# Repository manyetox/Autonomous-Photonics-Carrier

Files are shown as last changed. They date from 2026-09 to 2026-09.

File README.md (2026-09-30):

# Autonomous-Photonics-Carrier

**A source-available mobile robotics platform for autonomous and reconfigurable free-space photonics experiments.**

This repository contains the electronics, fabrication files, preliminary embedded firmware, and research documentation for my UCL Electrical and Electronic Engineering third-year BEng project. The carrier is intended to move standard optical hardware around a tabletop, estimate its own motion from complementary sensors, and ultimately support closed-loop optical experiment setup and alignment.

> **Project status — September 2026:** the **Platform V2 hardware design is finished**. Manufacturing and assembly are **partially complete and awaiting remaining parts**. The V2 main controller, motor/IMU board, and MA730 wheel-encoder board have been bench validated. The PAW3395 optical-flow board is the only current board that has not yet been experimentally validated. Full multi-sensor autonomous operation and the experiment-control software are still under development.

<p align="center">
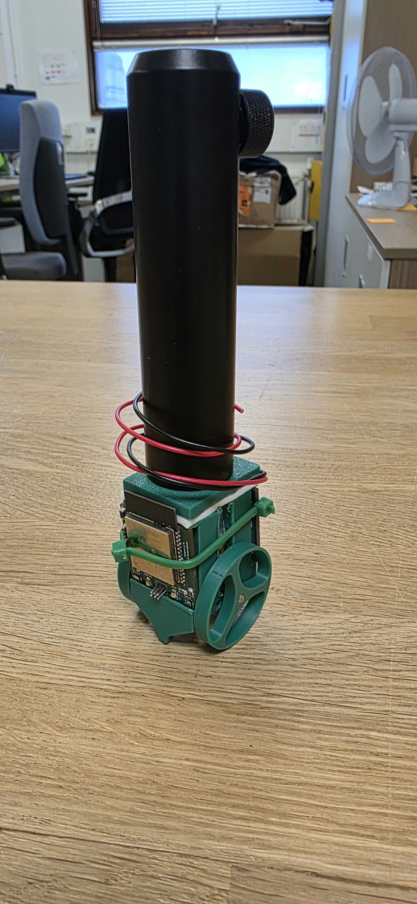
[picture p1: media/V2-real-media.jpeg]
Partially assembled Platform V2 carrier — front view
  
  &nbsp;&nbsp;
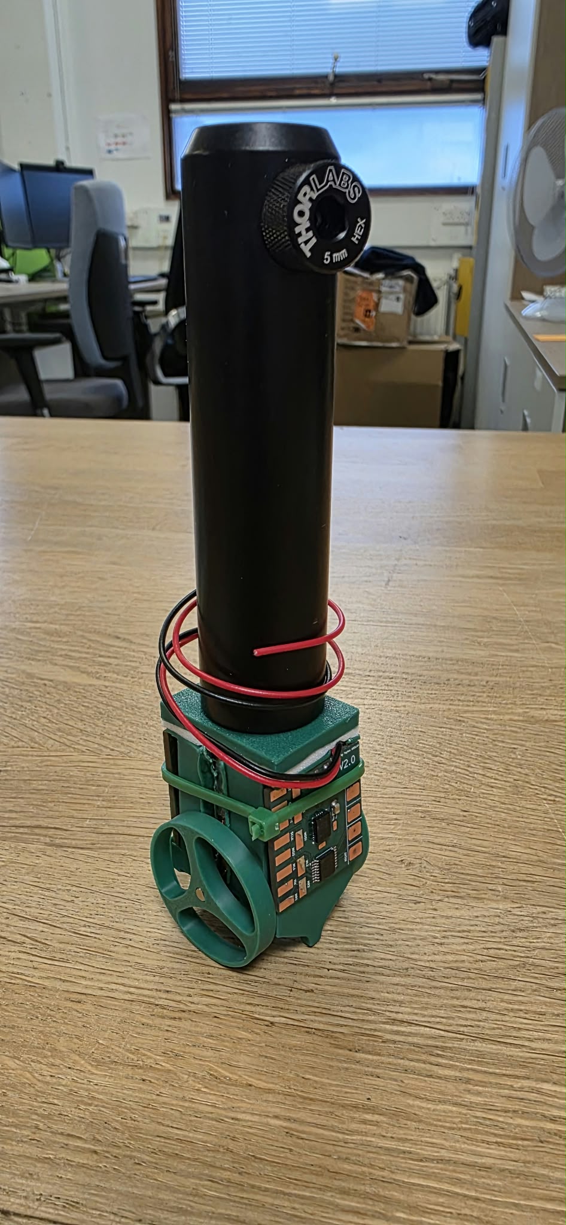
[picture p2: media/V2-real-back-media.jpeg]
Partially assembled Platform V2 carrier — rear view
  
</p>

<p align="center"><em>Current Platform V2 hardware during assembly. Front and rear views of the mobile carrier with the optical-post interface installed. The mechanical and electrical design is complete, while final assembly is still awaiting the remaining parts.</em></p>

## Read this first: platform versions are not board revisions

There are only **two photonics-carrier platform generations** in this repository:

| System generation | Meaning | Status |
|---|---|---|
| **Platform V1** | First integrated/monolithic autonomous-photonics carrier electronics | Historical, validated, superseded by V2 |
| **Platform V2** | Current modular carrier architecture | Current design; system assembly in progress |

The numbers on individual V2 PCBs are **board-local revisions**, not new carrier generations. For example, **OFS-R2.1.1** means *Optical-Flow Sensor board revision 2.1.1*; it is still part of **Platform V2**. The same applies to **MB-R2.1**, **MDI-R2.0**, and **ENC-R1.0**.

See [`VERSIONING.md`](VERSIONING.md) before using fabrication files.

## Why this project exists

Free-space optical experiments are normally assembled and aligned manually. Even a simple setup can require repeated positioning of posts, lenses, polarisers, sources, detectors, and cameras. The long-term research question behind this project is whether a low-cost fleet of mobile optomechanical carriers can make parts of that process **reconfigurable, repeatable, measurable, and eventually autonomous**.

This repository focuses on the carrier layer: motion, embedded electronics, local sensing, and the interfaces needed for higher-level perception and closed-loop experiment control. It does **not** claim that autonomous optical alignment has already been solved; that is the experimental work this platform is intended to enable.

## Research questions

The project is being developed as an experimental research platform rather than only as a mobile-robot hardware build. The central question is:

> **Can a self-propelled optical post-holder module combine mobile positioning, multi-sensor localisation, and optical feedback to autonomously reconstruct and align repeatable free-space photonics experiments?**

The current evaluation is organised around six questions:

1. **Coarse positioning accuracy and repeatability** — How accurately can a carrier reach a commanded planar pose \((x, y, \psi)\), and how closely can it return to that pose over repeated trials? How are the results affected by approach direction, travel distance, wheel slip, payload, and table-surface conditions?
2. **Stationary stability** — How much translational and angular drift occurs while the carrier remains stationary on its wheels? How are the results affected by motor-hold strategy, payload centre of mass, battery voltage, and measurement duration?
3. **Localisation and sensor fusion** — What accuracy and robustness can be achieved using the MA730 wheel encoders, PAW3395 optical-flow sensor, BNO086 IMU, and planned overhead visual fiducials individually and in combination? In particular, can the fused estimate remain useful during wheel slip, short visual occlusion, and accumulated odometry drift?
4. **Closed-loop optical alignment and recovery** — Can optical feedback compensate for the residual mechanical error remaining after mobile positioning? What alignment error, convergence time, capture range, success rate, and recovery behaviour can be achieved?
5. **Experiment reconstruction and operating range** — Can one or more carriers reconstruct the same optical configuration on separate occasions and reproduce the same measurement? For which beam sizes, propagation distances, wavelengths, and classes of tabletop experiment is the achieved positioning performance sufficient?
6. **Compatibility, cost, and scalability** — Can the platform carry standard optical posts and common holders without permanent modification? What payload, centre-of-mass height, battery runtime, and cost per carrier are practical, and how does operation change when multiple carriers share the same workspace?

These questions are intended to map directly onto measurable experiments. Results will only be reported after the relevant mechanical, electronic, localisation, and optical-control subsystems have been implemented and experimentally characterised.

> **Design-evolution note:** the earliest research framing included an on-carrier screw-and-flexure fine-positioning stage and UWB ranging. Those ideas belong to the earlier design direction and are **not core Platform V2 subsystems**. Platform V2 instead focuses on a modular mobile carrier using wheel encoding, bottom optical flow, inertial sensing, planned overhead visual localisation, and later optical feedback. Fine optomechanical correction can be evaluated as a separate layer if required.

## Current Platform V2 architecture

```mermaid
flowchart LR
    B["1S LiPo / external power"] --> MB["MB-R2.1<br/>ESP32-WROOM-32UE mainboard"]
    MB --> MDI["MDI-R2.0<br/>TC78H651 + BNO086"]
    MDI --> LM["Left DC gearmotor"]
    MDI --> RM["Right DC gearmotor"]

    MB --> OFS["OFS-R2.1.1<br/>PAW3395 optical-flow board"]
    MB --> ENC["ENC-R1.0<br/>MA730 wheel encoder boards"]

    OFS --> REL["Relative tabletop motion"]
    ENC --> WHEEL["Wheel angle / odometry"]
    MDI --> IMU["Inertial orientation / motion"]

    CAM["Overhead camera + fiducials<br/>planned system layer"] --> HOST["Host perception + experiment software<br/>planned"]
    HOST --> MB

    REL --> FUSION["Pose estimation / sensor fusion<br/>planned"]
    WHEEL --> FUSION
    IMU --> FUSION
    CAM --> FUSION
```

The V2 redesign deliberately separates functions across small PCBs. This makes the system easier to manufacture, debug, replace, and revise than V1's dense integrated board.

### V2 hardware at a glance

| Board ID | Function | Key devices | PCB | Current state |
|---|---|---|---|---|
| **MB-R2.1** | Main controller / power / breakout | ESP32-WROOM-32UE, NCP186 3.3 V LDO | 4-layer, ~25 × 27.1 mm | **Validated** |
| **MDI-R2.0** | Dual motor drive + IMU | TC78H651FGN, BNO086 | 4-layer, ~25 × 27 mm | **Validated** |
| **OFS-R2.1.1** | Bottom optical-flow sensing | PAW3395, AP2127K-1.8 | 2-layer, ~19.3 × 24.0 mm | **Not yet experimentally validated** |
| **ENC-R1.0** | Wheel-angle sensing | MA730 magnetic encoder | 2-layer, ~20 × 16.8 mm | **Validated** |

<p align="center">
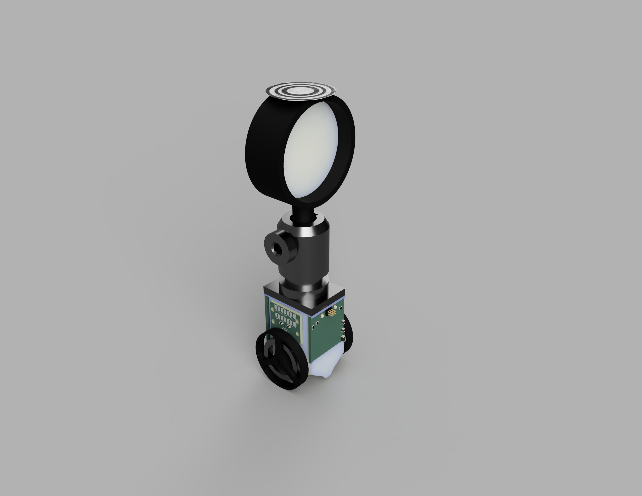
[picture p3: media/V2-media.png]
Platform V2 mechanical and electronics render
  
</p>

<p align="center"><em>Platform V2 design render. The current generation uses a modular electronics architecture so sensing, motor control, and the main controller can be manufactured, debugged, and revised independently.</em></p>

## Design evolution

### Platform V1 — integrated architecture

V1 placed most functions on one approximately **50 × 50 mm, 8-layer PCB**. The design included an **ESP32-S3-WROOM-1**, **DWM3000 UWB**, **BNO086 IMU**, **two TMC5041 stepper-controller ICs**, **DRV8231 motor-driver stages**, and the associated power and USB circuitry. It was a useful integration exercise and was built around the original concept of combining coarse mobile motion with local stepper/flexure positioning.

<p align="center">
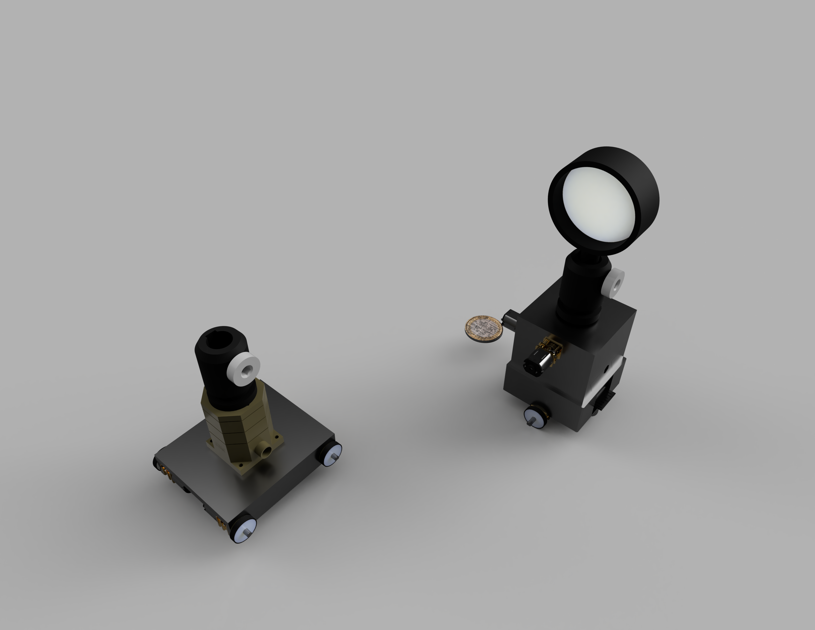
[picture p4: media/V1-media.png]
Platform V1 carrier concept render
  
</p>

<p align="center"><em>Platform V1 concept. The first carrier generation combined the mobile base with local optomechanical positioning and concentrated most of the electronics onto a single integrated PCB.</em></p>

### Why V2 changed direction

The current architecture intentionally moves away from putting every possible function on one carrier PCB. The main reasons were:

- **Modularity:** sensor and motor electronics can be revised without remanufacturing the controller.
- **Debuggability:** faults can be isolated board-by-board.
- **Lower manufacturing risk:** smaller boards and fewer tightly coupled subsystems.
- **Sensor strategy:** PAW3395 relative optical tracking, MA730 wheel angle, BNO086 inertial data, and planned overhead fiducials provide complementary information without retaining UWB as a core requirement.
- **Fine alignment separation:** the mobile base focuses on coarse positioning and repeatability. Very fine optical correction can be implemented as a separate optomechanical layer instead of forcing stepper/flexure hardware into every mobile carrier.
- **Cost and repeatability:** the architecture is intended to scale to multiple carriers, so unnecessary per-carrier complexity matters.

The V1 source is retained because it documents the design path and may still be useful to researchers interested in a more integrated architecture.

### Legacy reference — pre-project mobile robotics hardware

Before the dedicated photonics-carrier generations, I developed a more general mobile-robot electronics platform. It is retained in [`hardware/legacy-reference`](hardware/legacy-reference/) because several practical design lessons carried into this project, but it is **not Platform V0** and should not be treated as part of the carrier version sequence.

<p align="center">
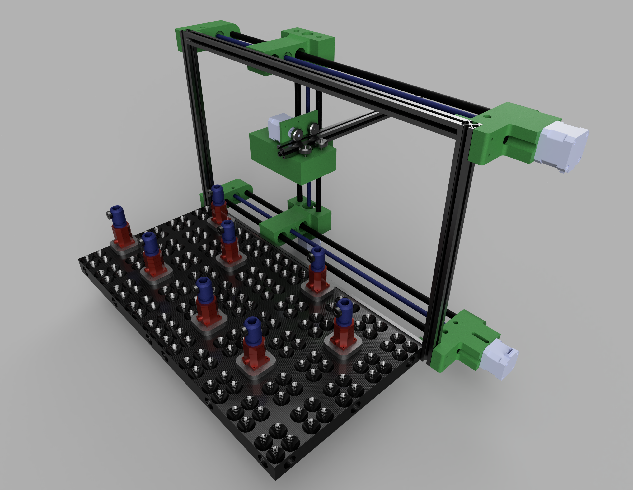
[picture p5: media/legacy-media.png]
Legacy mobile robotics reference hardware
  
</p>

<p align="center"><em>Legacy mobile-robot reference design retained for engineering context. It predates the autonomous-photonics carrier and is included only to document relevant design heritage.</em></p>

## Repository map

```text
Autonomous-Photonics-Carrier/
├── hardware/
│   ├── platform-v1/                 # Historical integrated carrier
│   ├── platform-v2/
│   │   ├── mainboard/MB-R2.1/
│   │   ├── motor-driver-imu/MDI-R2.0/
│   │   ├── optical-flow/OFS-R2.1.1/
│   │   └── wheel-encoder/ENC-R1.0/
│   └── legacy-reference/            # Pre-project robot electronics; not a platform version
├── firmware/preliminary/            # Safe preliminary ESP32 firmware scaffold
├── software/                        # Planned host-side autonomy / experiment software
├── docs/                            # Architecture, methods, validation, manufacturing notes
├── data/                            # Experimental-data conventions; no results claimed yet
├── media/                           # Image/video placeholders
├── VERSIONING.md
├── CHANGELOG.md
├── CITATION.cff
└── LICENSE.md
```

## Hardware source and fabrication files

Native **KiCad source files** are provided alongside fabrication outputs. Current fabrication packages are separated from superseded board revisions so that a Gerber revision cannot be mistaken for a platform generation.

Start here:

- [Platform V1 hardware](hardware/platform-v1/README.md)
- [Platform V2 hardware](hardware/platform-v2/README.md)
- [V2 mainboard — MB-R2.1](hardware/platform-v2/mainboard/MB-R2.1/README.md)
- [Motor/IMU — MDI-R2.0](hardware/platform-v2/motor-driver-imu/MDI-R2.0/README.md)
- [Optical flow — OFS-R2.1.1](hardware/platform-v2/optical-flow/OFS-R2.1.1/README.md)
- [Wheel encoder — ENC-R1.0](hardware/platform-v2/wheel-encoder/ENC-R1.0/README.md)
- [Manufacturing guide](docs/manufacturing.md)

The CSV BOMs in the board folders were auto-extracted from the KiCad PCB files to make review easier. **They are not a substitute for checking the schematic and part datasheets before ordering.**

## Preliminary firmware

A deliberately conservative PlatformIO/Arduino scaffold is included in [`firmware/preliminary`](firmware/preliminary/README.md). It establishes the intended embedded-software structure, status reporting, motor-control abstraction, serial command interface, and placeholders for BNO086, PAW3395, and MA730 integration.

It is **not the final autonomy firmware** and it is **not presented as experimentally validated software**. Peripheral signal-to-GPIO assignment is left disabled by default wherever the uploaded hardware files do not prove the final system interconnect unambiguously. This prevents a public repository from presenting guessed pin mappings as fact.

The preliminary firmware and parts of the repository/software scaffolding were prepared with assistance from **OpenAI ChatGPT 5.6** and then reviewed against the project hardware files. See [`AI_ASSISTANCE.md`](AI_ASSISTANCE.md).

## Planned sensing and autonomy stack

The intended estimation hierarchy is complementary rather than relying on a single sensor:

1. **Wheel angle / odometry:** MA730 magnetic encoders provide direct rotational information at the drivetrain.
2. **Bottom optical flow:** PAW3395 provides high-rate relative motion against the tabletop and can expose wheel-slip/odometry disagreement.
3. **IMU:** BNO086 provides inertial orientation/motion information and short-term dynamic context.
4. **Overhead fiducials:** a camera observing AprilTags or similar fiducials is planned as a global absolute pose reference and recovery mechanism.
5. **Optical feedback:** experimental signals can eventually be incorporated into the control loop so the carrier optimises the *optical result*, not only geometric pose.

Sensor fusion, global localisation, multi-carrier coordination, and optical-feedback optimisation are **planned software work**; they are not claimed as completed results in this repository.

## Research measurements this platform is intended to support

The repository is organised so that later results can be reproduced rather than reported only as a final demo. The principal measurements are:

- planar pose accuracy in **x, y, and yaw** against an external reference;
- **return-to-pose repeatability** over repeated move-away-and-return cycles;
- **stationary drift** and accumulated odometry drift;
- wheel-encoder, optical-flow, and IMU disagreement under controlled motion;
- recovery from deliberate slip or localisation error;
- carrier-to-carrier consistency if multiple units are built;
- cost per carrier and sensitivity to inexpensive mechanical components;
- success rate of a defined optical alignment task.

See [`docs/research-methodology.md`](docs/research-methodology.md) and [`docs/validation.md`](docs/validation.md). Until those experiments are complete, target resolutions or simulated estimates should not be read as measured performance.

For the research context behind the architecture, see [`docs/related-work.md`](docs/related-work.md).

## Research context and selected related work

This project sits between **robotic optical alignment**, **autonomous laboratories**, and **mobile multi-sensor robotics**. The most directly relevant prior work is summarised here; the longer discussion belongs in [`docs/related-work.md`](docs/related-work.md).

- **OptoMate / AI-Driven Robotics for Optics** demonstrates a general-purpose robotic approach to physically assembling and aligning free-space optical experiments using computer vision, robotic manipulation, and AI-assisted control [1]. It is a particularly close research neighbour, but it uses an external robotic manipulator rather than making each optical element independently mobile.
- **Choi et al.** present a closed-loop framework for robotic optical assembly, alignment, and self-recovery [2]. This is directly relevant to the carrier's long-term objective of detecting misalignment, correcting it from measurement feedback, and recovering after a disturbance.
- **Rakhmatulin et al.** review automated laser-optics alignment, including optimisation and machine-learning approaches [3]. Their review motivates treating the optical signal itself as a feedback variable rather than assuming that geometric positioning alone is sufficient.
- **Fang and Savransky** show automated alignment of a reconfigurable optical system using focal-plane sensing and Kalman filtering [4], providing an example of image-based estimation driving corrective optical motion.
- **Szymanski et al.** demonstrate the broader self-driving-laboratory concept in which robotics, measurement, and computational decision-making form a closed experimental loop [5]. The present project explores a different physical layer: making the experimental optical hardware itself reconfigurable on the tabletop.

Commercial active-alignment systems from companies such as Physik Instrumente provide useful industrial context: high-precision automated optical alignment is already practical, but such systems are generally built around dedicated stages and predefined alignment tasks rather than low-cost independently mobile optical carriers [6].

The distinction matters: this repository does **not** claim that the individual techniques above are new. The research question is whether coarse mobile positioning, complementary low-cost sensing, standard optomechanical compatibility, and closed-loop optical feedback can be combined into a scalable carrier architecture for reconfigurable free-space experiments.

## Selected references

1. S. Z. Uddin, S. Vaidya, S. Choudhary, Z. Chen, R. K. Salib, L. Huang, D. R. Englund, and M. Soljačić, **“AI-Driven Robotics for Optics,”** arXiv:2505.17985, 2025. https://doi.org/10.48550/arXiv.2505.17985
2. S. Choi, S. Vaidya, C. Silva, S. Z. Uddin, S. B. Shuvo, S. Choudhary, and M. Soljačić, **“A Framework for Closed-Loop Robotic Assembly, Alignment and Self-Recovery of Precision Optical Systems,”** arXiv:2603.21496, 2026. https://doi.org/10.48550/arXiv.2603.21496
3. I. Rakhmatulin, D. Risbridger, R. Carter, M. J. D. Esser, and M. S. Erden, **“A Review of Automation of Laser Optics Alignment with a Focus on Machine Learning Applications,”** *Optics and Lasers in Engineering*, vol. 173, 107923, 2024. https://doi.org/10.1016/j.optlaseng.2023.107923
4. J. Fang and D. Savransky, **“Automated Alignment of a Reconfigurable Optical System Using Focal-Plane Sensing and Kalman Filtering,”** arXiv:1608.07550, 2016. https://arxiv.org/abs/1608.07550
5. N. J. Szymanski *et al.*, **“An Autonomous Laboratory for the Accelerated Synthesis of Inorganic Materials,”** *Nature*, vol. 624, pp. 86–91, 2023. https://doi.org/10.1038/s41586-023-06734-w
6. PI (Physik Instrumente), **“Active Photonics Alignment Systems / Fiber Optic Alignment Stages,”** product and application documentation. https://www.pi-usa.us/en/products/photonics-alignment-solutions

## Project information

**Author:** Taylan Arslan  
**Programme:** UCL Electrical and Electronic Engineering — BEng third-year project, 2026–27  
**Project supervisor:** Prof. Kaan Akşit  
**EEE co-supervisor:** Thomas Gilbert

The supervisors are acknowledged for academic supervision; this repository is maintained by the author and is **not an official UCL product or endorsement**.

## Contributing

Research feedback, reproducibility reports, bug findings, and non-commercial improvements are welcome. Please read [`CONTRIBUTING.md`](CONTRIBUTING.md) before opening a pull request. In particular, use the versioning vocabulary above when discussing hardware revisions.

## Licensing

This repository is intentionally **source-available for non-commercial research, education, and personal experimentation**, but it does **not** grant commercial-use rights under its public licences.

- Hardware design files, documentation, diagrams, and repository media: **CC BY-NC 4.0**.
- Firmware and software: **PolyForm Noncommercial License 1.0.0**.
- Commercial use requires a **separate written commercial licence** from the author.

Because of the non-commercial restriction, this project should **not** be described as OSHWA-compliant “open-source hardware.” See [`LICENSE.md`](LICENSE.md) for the exact scope and important IP limitations.

## Safety and experimental responsibility

This is research hardware, not a certified product. Re-check power rails, polarity, motor current, battery protection/charging, connector orientation, clearances, and fabrication outputs before use. If the carrier is used around lasers or other optical sources, follow the laboratory's laser-safety procedures; this repository does not replace a risk assessment or device datasheet.

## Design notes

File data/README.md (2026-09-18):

# Experimental data

No positioning-performance dataset is claimed in this repository snapshot yet.

When experiments begin, use the structure in `docs/reproducibility.md`. Keep raw sensor/ground-truth logs immutable and store processed results separately.

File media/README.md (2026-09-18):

# Media placeholders

The repository is intentionally usable before final photographs are ready. Suggested filenames to add later:

- `hero-v2-carrier.jpg` — assembled Platform V2 carrier / main README image.
- `platform-v1-board.jpg` — assembled or rendered V1 integrated PCB.
- `v2-electronics-stack.jpg` — V2 mainboard and daughterboards together.
- `mb-r2.1.jpg` — V2 mainboard close-up.
- `mdi-r2.0.jpg` — motor/IMU board close-up.
- `ofs-r2.1.1.jpg` — PAW3395 board underside/lens assembly.
- `enc-r1.0.jpg` — MA730 encoder with magnet arrangement.
- `carrier-chassis.jpg` — mechanical carrier and optical post mount.
- `validation-setup.jpg` — overhead camera / tabletop test setup.
- `optical-demo.jpg` — eventual optical alignment experiment.

The visible text placeholders in the Markdown files can be replaced by normal Markdown images when these files are available.

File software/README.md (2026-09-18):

# Host software — planned

The host-side autonomy and experiment-control software is still planned rather than presented as complete. This directory documents the intended boundaries so that later software development remains compatible with the hardware.

## Planned modules

- **Global perception:** overhead camera calibration, fiducial/AprilTag detection, carrier identification, and global x/y/yaw pose.
- **Pose fusion:** combine camera, wheel angle, PAW3395 relative motion, and BNO086 information with explicit uncertainty handling.
- **Motion planning/control:** convert target table poses into carrier trajectories while handling obstacles and multiple carriers.
- **Experiment model:** represent optical components, carrier identities, and desired experimental topology.
- **Optical feedback:** use detector/camera/experiment measurements to refine physical alignment.
- **Logging:** synchronised sensor, command, pose, and optical-data capture for reproducible experiments.

## Interface philosophy

The embedded controller should own fast local actuation and low-level safety; the host should own global perception, experiment logic, optimisation, and data logging. This split keeps high-level research algorithms easy to modify without making the real-time motor-control path depend on a desktop process.

## AI assistance

Initial software architecture notes and the preliminary embedded scaffold were prepared with some assistance from OpenAI ChatGPT 5.6. Future implemented algorithms should be reviewed, tested, and documented in the same way as any other research code.

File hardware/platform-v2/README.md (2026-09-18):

# Platform V2 — current modular architecture

Platform V2 is the current carrier architecture. It is a **system generation**, not a PCB revision number.

Current boards:

- **MB-R2.1** — main controller/power/breakout
- **MDI-R2.0** — motor driver + BNO086 IMU
- **OFS-R2.1.1** — PAW3395 optical-flow sensor
- **ENC-R1.0** — MA730 wheel encoder

The electronics design is finished. Manufacturing/assembly of the complete carrier is still in progress while remaining parts arrive.

Three of the four current V2 board designs have been bench validated; OFS-R2.1.1 remains to be experimentally validated.

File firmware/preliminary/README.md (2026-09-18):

# Preliminary Platform V2 firmware scaffold

This is a **starting point**, not finished autonomous-carrier firmware.

It is intentionally conservative:

- targets the ESP32-WROOM-32UE main controller through the generic PlatformIO `esp32dev` board definition;
- controls the confirmed **IO13 status LED**;
- exposes a raw ADC diagnostic for the mainboard ADC-labelled net;
- defines a dual-H-bridge motor abstraction but refuses to drive motors until final GPIO mappings are supplied;
- provides serial commands for status/stop/motor testing;
- provides explicit placeholder interfaces for BNO086, PAW3395, and MA730 integration;
- performs no autonomous motion at boot.

The daughterboard connector signal names are known from KiCad, but the final physical signal-to-ESP32 interconnect is not encoded here unless it is unambiguous. This is deliberate: public firmware should not turn a guessed harness mapping into an apparent design fact.

## Build

Install PlatformIO and run:

```bash
pio run
```

Upload/monitor commands depend on the programmer/serial arrangement used with the TC2030/mainboard.

## First bring-up sequence

1. Build and flash with all peripheral pin assignments left disabled.
2. Confirm boot messages and IO13 LED heartbeat.
3. Confirm the actual daughterboard-to-mainboard wiring from the assembled carrier.
4. Populate `include/board_config.h` with the final GPIO numbers.
5. Test one motor at a time with the carrier lifted and a current-limited supply.
6. Integrate BNO086, MA730, then PAW3395 drivers individually.
7. Only after sensor sign/frame checks should closed-loop motion be enabled.

## AI assistance

This preliminary scaffold was written with some assistance from **OpenAI ChatGPT 5.6**, using the project's KiCad net names and existing architecture as context. It has not yet been validated as the final firmware and should be reviewed against device datasheets during implementation.

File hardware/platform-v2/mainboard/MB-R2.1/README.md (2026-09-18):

# MB-R2.1 — Platform V2 mainboard

**Platform:** V2  
**Board revision:** MB-R2.1  
**Status:** validated; current  
**PCB:** 4 layers, approximately 25 × 27.1 mm

## Function

MB-R2.1 is the central controller and power/breakout board. It intentionally avoids embedding every sensor/actuator subsystem so that daughterboards can be changed independently.

## Key hardware

- ESP32-WROOM-32UE
- NCP186-series 3.3 V LDO design
- TC2030 programming connector
- two 13-pin expansion headers
- IO13 user/status LED
- 3.3 V power indicator

See `docs/interfaces-and-pinouts.md` for connector nets.

## Fabrication

Use only `fabrication/current/MB-R2.1-gerbers.zip` for the current board. `archive/MB-R2.0-gerbers-superseded.zip` is kept only for design history.

> **Image placeholder:** I will add a photograph of the assembled MB-R2.1 here later.

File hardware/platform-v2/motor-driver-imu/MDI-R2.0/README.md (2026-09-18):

# MDI-R2.0 — motor driver + IMU

**Platform:** V2  
**Board revision:** MDI-R2.0  
**Status:** validated; current  
**PCB:** 4 layers, approximately 25 × 27 mm

## Function

This daughterboard combines low-speed differential-drive actuation with inertial sensing.

## Key hardware

- **TC78H651FGN** dual H-bridge motor driver
- **BNO086** 9-axis smart IMU
- SPI-oriented IMU interface signals
- separate motor output pads

The design is intended for the low-speed DC-gearmotor V2 drivetrain rather than the V1 stepper/flexure architecture.

See `docs/interfaces-and-pinouts.md` for the 13-pin connector net names.

> **Image placeholder:** I will add the assembled motor/IMU board and its motor wiring here later.

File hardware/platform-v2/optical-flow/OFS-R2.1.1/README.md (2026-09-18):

# OFS-R2.1.1 — PAW3395 optical-flow sensor

**Platform:** V2  
**Board revision:** OFS-R2.1.1  
**Status:** current design; **not yet experimentally validated**  
**PCB:** 2 layers, approximately 19.3 × 24.0 mm

## Function

This board mounts a bottom-facing PAW3395 optical tracking sensor so the carrier can measure relative motion against the tabletop independently of wheel rotation.

## Key hardware

- PAW3395 optical tracking sensor
- AP2127K-1.8 local 1.8 V LDO
- SPI (`SCLK`, `MOSI`, `MISO`, `nCS`)
- `MOTION` output
- lens/mechanical optical stack

The current schematic specifies **R3 = 2 MΩ**.

This board should not be described as working until the 1.8 V rail, SPI initialisation, motion data, lens height, and calibrated displacement have been tested on the assembled hardware.

> **Image placeholder:** I will add a photograph showing the PAW3395 lens and underside mounting here after validation.

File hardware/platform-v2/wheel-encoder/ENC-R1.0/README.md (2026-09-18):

# ENC-R1.0 — MA730 wheel encoder

**Platform:** V2  
**Board revision:** ENC-R1.0  
**Status:** validated; current  
**PCB:** 2 layers, approximately 20 × 16.8 mm

## Function

ENC-R1.0 measures wheel/shaft angle using the **MA730 magnetic angle sensor**. It replaces earlier exploration of sparse Hall-sensor edge counting with a more direct angle-sensing approach.

## Interfaces

- SPI: MOSI, MISO, SCLK, CS
- 3.3 V and GND
- optional A/B/Z outputs
- PWM output
- MGL/MGH magnetic-field diagnostic outputs

The magnetic target and air gap are part of the measurement system. Experimental records should identify the magnet geometry and mechanical spacing.

> **Image placeholder:** I will add the encoder mounted next to the final wheel/shaft magnet here later.

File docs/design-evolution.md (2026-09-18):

# Design evolution and engineering rationale

## Pre-project legacy controller

The repository includes an older general-purpose ESP32 robot-controller PCB under `hardware/legacy-reference/`. It is included only to show the engineering background that informed later motor-control and embedded-PCB decisions. It is **not Platform V0 or Platform V1**.

## Platform V1: integration-first

The first photonics-specific carrier used a dense 8-layer board. The architecture attempted to keep coarse motion, UWB localisation, inertial sensing, local stepper control, USB protection, and power electronics on one PCB. That approach offered compact integration, but it also coupled many experimental assumptions into one expensive board spin.

The most important V1 elements visible in the source are:

- ESP32-S3-WROOM-1 controller;
- DWM3000 UWB module;
- BNO086 IMU;
- two TMC5041 stepper-controller ICs;
- DRV8231 motor-driver stages;
- TPS56528DDA power stage;
- a 50 × 50 mm, 8-layer PCB.

The local stepper/flexure concept made sense when the carrier was expected to perform coarse and fine motion itself. As the project matured, it became clearer that the mobile base and the fine optomechanical stage have different engineering requirements.

## Platform V2: modularity-first

V2 separates the carrier into replaceable functions. The mainboard is small and generic; the motor/IMU, optical-flow, and wheel-angle functions live on separate boards. This change supports several research goals:

- cheaper iteration on one subsystem;
- clearer fault isolation;
- easier comparison of alternative sensors;
- less dependence on a single monolithic PCB spin;
- simpler scaling to several carriers;
- easier future replacement of the MCU or sensor board.

### Why UWB is no longer core

UWB was useful as a coarse global-localisation idea, but the combination of overhead fiducials, bottom optical flow, wheel angle, and IMU data better matches the tabletop scale of the experiment while reducing radio hardware and calibration complexity. UWB remains documented in V1 rather than being silently erased from the design history.

### Why the stepper/flexure subsystem was removed from V2

Fine optical alignment can require much finer motion and better stiffness than a low-cost mobile base naturally provides. Instead of asking every carrier to contain a complete fine XYZ/yaw mechanism, V2 treats the mobile base as a coarse positioning and sensing platform. A premade piezo/fine stage or experiment-specific adjustment module can be added above the carrier when needed.

### Why PAW3395

The PAW3395 path was chosen after looking for a compact, actively available optical-tracking sensor suitable for high-resolution relative motion. It provides a direct relative-motion signal at the bottom of the carrier and gives the estimator information that is independent of wheel rotation.

### Why MA730

Early encoder exploration considered discrete magnets and Hall sensors. The current board instead uses an MA730 magnetic angle encoder. That moves the design from sparse edge counting toward direct angular measurement and also exposes A/B/Z and diagnostic outputs for alternative experiments.

## Academic interpretation

V1 and V2 should be treated as different experimental hardware architectures, not as a claim that V2 is already proven superior in measured localisation performance. V2 is preferred because of engineering modularity and the current research direction; quantitative comparison requires data.

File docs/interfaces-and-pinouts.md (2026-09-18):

# Electrical interfaces and pinouts

These tables are extracted from the current uploaded KiCad PCB net names. They document what the boards expose without inventing an unverified system-level harness mapping.

## MB-R2.1 mainboard

### J2 — 13-pin expansion header

| Pin | Net |
|---:|---|
| 1 | +3.3V |
| 2 | GND |
| 3 | IO_analog_ADC |
| 4 | IO34 |
| 5 | IO35 |
| 6 | IO32 |
| 7 | IO33 |
| 8 | IO25 |
| 9 | IO26 |
| 10 | IO27 |
| 11 | IO14 |
| 12 | IO12 |
| 13 | IO13 |

### J3 — 13-pin expansion header

| Pin | Net |
|---:|---|
| 1 | GND |
| 2 | IO23 |
| 3 | IO22-SCL |
| 4 | IO21-SDA |
| 5 | IO19 |
| 6 | IO18 |
| 7 | IO17 |
| 8 | IO16 |
| 9 | IO4 |
| 10 | +3.3V |
| 11 | +3.3V |
| 12 | Vin |
| 13 | GND |

### J1 — TC2030 programming header

| Pin | Net |
|---:|---|
| 1 | EN |
| 2 | +3.3V |
| 3 | U0TX |
| 4 | GND |
| 5 | U0RX |
| 6 | ESP_BOOT |

The onboard controllable LED is connected to **IO13** through its series resistor. The second LED is a 3.3 V power indicator.

## MDI-R2.0 motor-driver / IMU board — J1

| Pin | Net |
|---:|---|
| 1 | IMU_RST_N |
| 2 | IMU_CS_N |
| 3 | IMU_INT_N |
| 4 | SPI_SCLK |
| 5 | SPI_MISO |
| 6 | MOTOR_L_IN1 |
| 7 | Vin |
| 8 | MOTOR_R_IN2 |
| 9 | MOTOR_R_IN1 |
| 10 | MOTOR_L_IN2 |
| 11 | SPI_MOSI |
| 12 | PS1 |
| 13 | GND |

Motor outputs are broken out separately as Motor1 +/- and Motor2 +/-.

## OFS-R2.1.1 PAW3395 board — J3

| Pin | Net |
|---:|---|
| 1 | MOTION |
| 2 | SCLK |
| 3 | MOSI |
| 4 | MISO |
| 5 | nCS |
| 6 | VIN |
| 7 | GND |

The board locally generates **1.8 V** for the PAW3395 core using AP2127K-1.8.

## ENC-R1.0 MA730 board

### J1 — SPI / power

| Pin | Net |
|---:|---|
| 1 | MOSI |
| 2 | MISO |
| 3 | SCLK |
| 4 | CS |
| 5 | NC |
| 6 | +3.3V |
| 7 | GND |

### J2 — alternate/diagnostic outputs

| Pin | Net |
|---:|---|
| 1 | Z |
| 2 | B |
| 3 | A |
| 4 | NC |
| 5 | MGL |
| 6 | MGH |
| 7 | PWM |

## Important firmware note

The repository deliberately does not convert the daughterboard connector names above into guessed ESP32 GPIO assignments. The current firmware scaffold requires the final physical interconnect to be confirmed before those mappings are enabled. This is preferable to publishing a firmware pin map that merely looks plausible.

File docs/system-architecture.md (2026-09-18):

# System architecture

## Research objective

The carrier is a mobile embedded platform intended to support reconfigurable free-space photonics experiments. Its job is to transport an optical post/holder, estimate its planar motion, and expose control/sensing interfaces that higher-level software can use for closed-loop experiment automation.

The design deliberately separates **coarse mobile positioning** from **fine optical alignment**. The mobile base should move an element close enough and repeatably enough that an independent fine stage or optical-feedback loop can complete alignment when the experiment requires it.

## Platform V2 sensing model

No single low-cost sensor is expected to remain accurate under every condition. The V2 architecture therefore uses complementary information:

- **MA730 wheel encoders** — direct wheel-angle measurement; useful for local odometry but sensitive to slip and wheel/mechanical errors.
- **PAW3395 optical flow** — relative motion against the tabletop; can detect motion that wheel odometry does not explain and can reduce dependence on wheel geometry.
- **BNO086 IMU** — inertial orientation/dynamics; useful for yaw/short-term motion context but can drift if treated as the only absolute reference.
- **Overhead fiducial camera (planned)** — global absolute pose reference and recovery source.
- **Optical experiment signal (future)** — closes the loop on the experimental objective itself rather than pose alone.

The fusion algorithm is intentionally not fixed in hardware. An EKF, factor-graph approach, complementary estimator, or experiment-specific optimiser can be evaluated later against the same sensor suite.

## Motion architecture

The present mechanical concept uses a compact four-wheel carrier with left/right differential drive and low-speed N20-class gearmotors. Earlier design work targeted roughly 15–20 rpm operation from a 1S LiPo to favour controllability and torque over top speed. The exact mechanical chassis and motor BOM are not yet included in this repository release.

> **Image placeholder — chassis:** I will add the final carrier chassis and optical-post mounting arrangement here once the mechanical assembly is complete.

## Electrical partitioning

### MB-R2.1 mainboard

- ESP32-WROOM-32UE-N4-class module footprint/design.
- NCP186-series 3.3 V LDO design.
- TC2030 programming/debug connector.
- Two 13-pin expansion connectors that expose power and ESP32 signals.
- IO13 status LED plus a 3.3 V power indicator.

### MDI-R2.0 motor/IMU board

- TC78H651FGN dual H-bridge.
- BNO086 9-axis smart IMU.
- Motor output pads and power/interface connections.
- SPI-oriented IMU signal set in the current design.

### OFS-R2.1.1 optical-flow board

- PAW3395 optical tracking sensor.
- AP2127K-1.8 local 1.8 V regulator.
- SPI + motion-interrupt interface.
- Dedicated optical/lens mechanical requirements.

### ENC-R1.0 wheel encoder

- MA730 magnetic angle encoder.
- SPI interface.
- Optional A/B/Z, PWM, and magnetic-field status outputs broken out separately.

## Communications

The ESP32 provides the embedded control point. Host communication is expected to use a convenient research interface such as USB-serial during bring-up and Wi-Fi/Bluetooth or a higher-level network protocol later. The repository does not yet define the final multi-carrier networking protocol.

## Power strategy

V2 is built around a low-voltage battery-powered carrier. The mainboard provides 3.3 V logic regulation, while the PAW3395 board derives its required 1.8 V rail locally. Battery charging is expected to be external rather than implemented as an onboard charger in the current electronics.

## Scope boundaries

The following are intentionally outside the present completed-hardware claim:

- final carrier chassis and optical post adapter;
- production-ready battery enclosure/charger;
- complete sensor-fusion firmware;
- overhead-camera perception software;
- multi-carrier coordination;
- automatic closed-loop optical alignment;
- validated positioning-performance numbers.

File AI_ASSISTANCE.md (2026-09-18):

# AI assistance disclosure

The preliminary embedded-firmware scaffold in `firmware/preliminary/` and portions of the repository organisation/documentation were prepared with assistance from **OpenAI ChatGPT 5.6**.

The AI assistance was used for tasks such as code scaffolding, documentation structure, consistency checks, and converting the project's existing design decisions into public-facing technical documentation. The hardware schematics/PCB layouts, component decisions, physical assembly, and experimental validation remain the work/responsibility of the project author.

The preliminary firmware has **not** been presented as validated autonomy software. AI-generated or AI-assisted code should be reviewed against the relevant component datasheets and tested on hardware before it is relied upon experimentally.

Any future academic publication should follow the disclosure requirements of the relevant venue and institution at the time of submission.

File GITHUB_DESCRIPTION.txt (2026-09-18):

Source-available modular mobile carrier for autonomous photonics experiments using ESP32 control, optical flow, IMU sensing and magnetic wheel encoding.

Suggested GitHub topics:
autonomous-photonics, photonics, robotics, esp32, kicad, embedded-systems, sensor-fusion, optical-flow, paw3395, bno086, ma730, research-hardware, optomechanics

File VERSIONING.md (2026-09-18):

# Versioning and naming convention

This project uses **two independent version namespaces**. Keeping them separate is important for reproducibility.

## 1. Platform generation

A **Platform** version describes the overall system architecture.

- **Platform V1** — integrated/monolithic carrier electronics.
- **Platform V2** — modular carrier electronics; current architecture.

A daughterboard revision does **not** create a new platform generation.

## 2. Board revision

Each PCB has its own identifier:

| Board identifier | Human-readable name | Platform | Current? |
|---|---|---|---|
| **INT-R1.0.1** | Integrated V1 carrier PCB | Platform V1 | Historical |
| **MB-R2.1** | Mainboard | Platform V2 | Yes |
| **MDI-R2.0** | Motor Driver + IMU | Platform V2 | Yes |
| **OFS-R2.1.1** | Optical-Flow Sensor | Platform V2 | Yes |
| **ENC-R1.0** | Wheel Encoder | Platform V2 | Yes |

Therefore, **OFS-R2.1.1 is not “Platform V2.1.1.”** It is board revision 2.1.1 within Platform V2.

## Historical fabrication outputs

Older Gerbers are retained only inside `archive/` folders and are explicitly labelled as superseded. They are useful for design history but should not be sent to fabrication unless there is a specific reason to reproduce that revision.

## Firmware/software versions

Firmware and host software should be versioned independently from hardware. A future firmware release may support more than one hardware board revision, so firmware tags should not reuse PCB revision numbers.

Recommended future tags:

- `fw-v0.1.0`, `fw-v0.2.0`, ... for embedded firmware releases.
- repository release tags such as `release-2026-09` or semantic versions for curated archival snapshots.

Each experimental dataset should record **Platform generation + every installed board revision + firmware commit/tag**.

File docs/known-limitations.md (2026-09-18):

# Known limitations and design-review notes

This file intentionally records unresolved items rather than hiding them.

## System integration is not complete

Platform V2 is a finished electronics design but the physical carrier is still being assembled. Full autonomous operation has not yet been demonstrated in this repository release.

## PAW3395 board remains unvalidated

OFS-R2.1.1 is electrically simple relative to the larger boards, but it should still be treated as **unvalidated until measured**. Optical tracking sensors are sensitive to lens geometry, surface, height, sensor initialisation, and motion conditions.

## Peripheral-to-ESP32 mapping needs final system confirmation

The KiCad source clearly documents each board's connector nets, but the public firmware does not assume a daughterboard-to-mainboard GPIO mapping that has not been proven from the final assembled interconnect. The preliminary firmware therefore leaves these peripheral assignments disabled by default.

## Mainboard ADC network review item

In the uploaded MB-R2.1 PCB source, the network labelled `IO_analog_ADC_Battery_Meter` is connected through R27 to the R25/R26 divider, and R25 is shown tied to **+3.3 V** rather than `Vin`. If this network is intended as a battery-voltage monitor, that connection should be re-checked before relying on it as a battery measurement. The firmware consequently exposes only a raw diagnostic ADC path and does not claim calibrated battery voltage.

## Mechanical design not included yet

The archive supplied for this repository contains PCB STEP files but not the final carrier chassis, wheel geometry, encoder magnet mount, or optical-post adapter. Those mechanical parameters are essential to reproducible odometry and will need to be added when finalised.

## No production battery subsystem

There is no onboard battery charger/BMS presented here as a finished product. Use an appropriate protected cell and charger.

## No measured positioning specification yet

The architecture was designed for research into high-repeatability positioning, but a final x/y/yaw accuracy number would be premature until the complete sensor-fusion and ground-truth experiments are run.

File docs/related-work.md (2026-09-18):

# Related work and research context

This page places the **Autonomous-Photonics-Carrier** in its research context. It is intended as a concise engineering map of nearby work, not as an exhaustive literature review.

The central idea of this project is to investigate whether **small, comparatively low-cost mobile carriers can reposition standard free-space optical hardware on a tabletop, estimate their own pose from complementary sensors, and provide a hardware layer for later closed-loop optical alignment**. That emphasis is different from building a single general-purpose robotic manipulator: the carrier itself becomes part of the reconfigurable optical table.

## OptoMate / AI-driven robotics for free-space optics

**S. Z. Uddin et al., “AI-Driven Robotics for Free-Space Optics,” arXiv:2505.17985 (2025).**  
<https://arxiv.org/abs/2505.17985>

OptoMate combines generative AI, computer vision, precision robotics, robotic pick-and-place, and fine-alignment tooling to automate free-space optical experiments. It is an important demonstration that optical setup generation, physical assembly, alignment, and measurement can be connected into one autonomous workflow.

### Relationship to this project

The Autonomous-Photonics-Carrier approaches the physical layer from a different direction. Rather than relying primarily on a robot arm to place optical components, this project explores **distributed mobile modules that carry the optical elements themselves**. The two approaches should therefore be viewed as related but not equivalent architectures.

The most relevant lessons for this project are:

- geometric placement alone is not sufficient for a useful optical experiment;
- coarse positioning and fine optical alignment should be treated as different control regimes;
- computer vision can provide a global reference, while local sensors can provide faster relative motion information;
- the final success metric should include the quality of the optical experiment, not only robot pose error.

## Closed-loop robotic optical assembly and self-recovery

**S. Choi et al., “A Framework for Closed-Loop Robotic Assembly, Alignment and Self-Recovery of Precision Optical Systems,” arXiv:2603.21496 (2026).**  
<https://arxiv.org/abs/2603.21496>

This work demonstrates a closed-loop framework for robotic construction, alignment, maintenance, and recovery of precision optical systems, including autonomous construction of a tabletop laser cavity. It is particularly relevant because it treats optical alignment as an iterative feedback problem rather than a one-shot geometric placement task.

### Relationship to this project

For the Autonomous-Photonics-Carrier, this supports the architectural decision to keep a distinction between:

1. **coarse mobile positioning** of the carrier;
2. **pose estimation and recovery** using external and onboard sensing; and
3. **fine alignment using optical feedback and/or a dedicated fine-positioning mechanism**.

The current repository concentrates on the first two hardware layers. Closed-loop optical optimisation remains future experimental and software work and is not claimed as a completed capability.

## UbiSwarm and small tabletop multi-robot systems

**L. H. Kim and S. Follmer, “UbiSwarm: Ubiquitous Robotic Interfaces and Investigation of Abstract Motion as a Display,” Proceedings of the ACM on Interactive, Mobile, Wearable and Ubiquitous Technologies, 1(3), 2017.**  
DOI: <https://doi.org/10.1145/3130931>  
Project page: <https://shape.stanford.edu/research/UbiSwarm/>

UbiSwarm is not a photonics platform, but it is relevant to the **physical architecture of many small mobile robots sharing a tabletop workspace**. It provides a useful precedent for thinking about compact mobile units, multi-robot motion, and scalable distributed physical systems.

### Relationship to this project

The useful connection is at the robotics-system level rather than the optical-control level. The Autonomous-Photonics-Carrier similarly aims to make the mobile unit small enough that multiple carriers could coexist around an experiment, while retaining enough onboard sensing and control to support repeatable motion.

## Position of this repository

The project sits at the intersection of three research directions:

- **autonomous photonics**, where optical experiments are assembled, aligned, measured, and recovered with increasingly closed-loop automation;
- **mobile modular robotics**, where distributed units can reconfigure the physical arrangement of a workspace; and
- **embedded sensor fusion**, where wheel angle, optical flow, inertial sensing, and external vision provide complementary estimates of motion and pose.

The current contribution of this repository is therefore intentionally narrow and testable: **a documented mobile-carrier hardware platform and a reproducible basis for measuring whether this architecture is accurate, repeatable, stable, and practical enough to support later autonomous photonics experiments.**

## Scope note

References on this page are included to explain engineering context. Their inclusion does not imply that this project reproduces or matches the performance of those systems. Any future quantitative comparison should use clearly defined experimental conditions and measured results rather than architectural similarity alone.

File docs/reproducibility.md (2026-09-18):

# Reproducibility checklist

A build or experiment is only reproducible if someone else can determine exactly what was used.

For each published result, record:

- Platform V1 or Platform V2;
- every PCB board ID/revision;
- exact fabrication package or commit;
- component substitutions;
- final mechanical CAD/revision;
- wheel/motor/magnet geometry;
- battery and supply configuration;
- firmware commit/tag;
- host-software commit/tag;
- calibration files;
- raw data;
- processing script/notebook version;
- environmental/tabletop conditions;
- ground-truth method and calibration;
- experiment protocol and exclusion criteria.

## Recommended dataset layout

```text
data/
└── YYYY-MM-DD_experiment-name/
    ├── README.md
    ├── metadata.yaml
    ├── raw/
    ├── calibration/
    ├── processed/
    └── figures/
```

Do not commit large raw datasets blindly to normal Git history. Curated datasets can later be archived separately and referenced from the repository.

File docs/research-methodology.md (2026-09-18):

# Research methodology

## Core questions

The platform is designed to make the following questions experimentally answerable:

1. How accurately can a low-cost mobile carrier estimate and control planar **x, y, yaw** pose on an optical table?
2. How repeatable is the carrier when asked to leave and return to the same pose?
3. How much drift is contributed by wheel odometry, optical flow, IMU, and the estimator itself?
4. Does combining wheel angle, optical flow, inertial sensing, and global vision improve recovery from slip or accumulated error?
5. What accuracy/repeatability is required before optical feedback can reliably complete alignment?
6. What is the cost and complexity per carrier, and how does that scale to multiple modules?

## Terminology

### Accuracy

Closeness of an estimated/commanded pose to an external ground-truth pose.

### Precision

Spread of repeated measurements under nominally identical conditions. High precision alone does not imply accuracy.

### Repeatability

Ability to return to the same physical pose under the same procedure. This is especially important for reconfigurable experiments.

### Resolution

Smallest change the sensing/control chain can meaningfully distinguish. Sensor count resolution should not be reported as system positioning accuracy.

### Drift

Change in estimated or physical pose over time without an intended command. Drift must be separated into sensor, estimator, thermal, mechanical, and true-motion components where possible.

## Ground truth

The planned overhead fiducial camera is the natural external reference for planar motion, but it should be calibrated and its own uncertainty reported. A high-resolution camera estimate is still a measurement system, not absolute truth.

For selected tests, independent mechanical references (ruler/linear stage/dial indicator/precision fixture) can be useful to validate the camera calibration.

## Statistical reporting

For repeated experiments, report distributions rather than only best-case values. Useful statistics include:

- sample count;
- mean signed error;
- mean absolute error;
- RMS error;
- standard deviation;
- 50th/95th percentile radial error;
- yaw error separately from translation;
- failure/success count for alignment tasks.

## Avoiding misleading claims

- Do not turn encoder quantisation into a claimed positioning accuracy.
- Do not call a simulated or theoretical value “measured.”
- Do not pool data from different hardware revisions without recording the revision.
- Do not tune on the same dataset used for final evaluation without saying so.
- Do not hide failed runs; define exclusion criteria in advance.

## Suggested experiment record

Each run should record at minimum:

- timestamp/run ID;
- Platform generation;
- MB/MDI/OFS/ENC board revisions;
- firmware commit/tag;
- host-software commit/tag;
- wheel diameter and track width;
- motor/gearbox configuration;
- battery voltage/state;
- tabletop/surface description;
- PAW3395 lens/height configuration;
- encoder magnet configuration;
- camera calibration identifier;
- command trajectory;
- raw sensor streams;
- ground-truth stream;
- processed estimate;
- relevant optical measurement.

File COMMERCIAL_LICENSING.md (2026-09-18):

# Commercial licensing

The public licences in this repository permit the stated **non-commercial** uses only. Commercial copying, adaptation, distribution, incorporation of the copyrighted repository materials into a commercial product, or other commercial exploitation requires a separate written commercial licence from the author.

Commercial licences may be negotiated for a fee. To enquire, contact **Taylan Arslan** through the GitHub profile associated with this repository or open a repository issue titled **Commercial licensing enquiry** without posting confidential business information.

No commercial rights are granted merely by starting a discussion. Terms, scope, attribution, warranty, support, field of use, and fees must be agreed separately in writing.

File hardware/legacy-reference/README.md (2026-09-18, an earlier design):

# Legacy robot-controller reference — not a photonics platform version

This folder contains a pre-project ESP32 robot-controller design that influenced later embedded/motor-control work.

It is included only for design history and reusable engineering reference. It is **not** “Platform V0,” “Platform V1,” or a current photonics-carrier PCB.

Do not use its filename/versioning vocabulary when citing the autonomous-photonics carrier.

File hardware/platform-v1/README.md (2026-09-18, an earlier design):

# Platform V1 — integrated carrier

Platform V1 is the first photonics-specific carrier architecture. It is retained as a **validated historical design** and should not be confused with the legacy robot controller.

The current archived board identifier is **INT-R1.0.1**.

Key features visible in the PCB source include ESP32-S3-WROOM-1, DWM3000 UWB, BNO086, dual TMC5041 stepper-control ICs, DRV8231 motor-driver stages, and an 8-layer 50 × 50 mm PCB.

V1 is superseded by Platform V2 for ongoing work because V2 separates controller, motor/IMU, optical-flow, and wheel-encoder functions into smaller boards.

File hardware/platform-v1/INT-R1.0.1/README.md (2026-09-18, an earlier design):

# INT-R1.0.1 — Platform V1 integrated PCB

**Platform:** V1  
**Board revision:** INT-R1.0.1  
**Status:** validated historical hardware; superseded by Platform V2  
**PCB:** 8 layers, approximately 50 × 50 mm

## Main subsystems

- ESP32-S3-WROOM-1 controller
- DWM3000 UWB module
- BNO086 IMU
- 2 × TMC5041 stepper-controller ICs
- 2 × DRV8231 motor-driver stages
- TPS56528DDA power stage
- USB/ESD and breakout interfaces

`source/` contains the editable KiCad files. `fabrication/current/` contains the final retained V1 Gerber/drill package. Earlier schematic export is kept only in `archive/`.

> **Image placeholder:** I will add a V1 board photograph or render here later.

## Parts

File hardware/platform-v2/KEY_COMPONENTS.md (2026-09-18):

# Platform V2 key component selections

This is a curated component summary, not a complete purchasing BOM.

| Subsystem | Selected part / specification | Notes |
|---|---|---|
| Main MCU | ESP32-WROOM-32UE | External-antenna ESP32 module used on MB-R2.1 |
| 3.3 V regulator | NCP186AMX330TAG | Low-Iq 3.3 V / 1 A class LDO selection |
| Motor driver | TC78H651FGN,EL | Dual H-bridge on MDI-R2.0 |
| IMU | BNO086 | 9-axis smart IMU on MDI-R2.0 |
| Optical flow | PAW3395 | Bottom relative-motion sensor |
| Optical-flow 1.8 V LDO | AP2127K-1.8TRG1 | Local regulator on OFS board |
| Optical sensor lens | LOAE-LSI1 preferred / LM19-LSI alternative | Mechanical optical stack must be validated |
| Wheel angle | MA730 | Magnetic angle encoder on ENC-R1.0 |
| Main bulk capacitor | Murata GRM31CR60J107KEA8K, 100 µF, 6.3 V, X5R | Selected low-profile bulk capacitor where applicable |
| Drivetrain target | Low-speed N20-class geared DC motors, roughly 15–20 rpm target | Mechanical selection/integration; final motor BOM not yet released here |

Generic passives may be substituted only after checking voltage rating, tolerance, package fit, ESR/decoupling role, and the relevant device datasheet.

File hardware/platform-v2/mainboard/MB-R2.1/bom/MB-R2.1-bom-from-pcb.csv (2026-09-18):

Quantity | References | Value / Part | Footprint | Source
2 | C15, C33 | 0.1u | Capacitor_SMD:C_0805_2012Metric_Pad1.18x1.45mm_HandSolder | Auto-extracted from KiCad PCB; verify against schematic before ordering
1 | FB1 | 100 Ω @ 100 MHz | Inductor_SMD:L_1206_3216Metric | Auto-extracted from KiCad PCB; verify against schematic before ordering
1 | C20 | 100n | Capacitor_SMD:C_0805_2012Metric_Pad1.18x1.45mm_HandSolder | Auto-extracted from KiCad PCB; verify against schematic before ordering
2 | R28, R8 | 10k | Resistor_SMD:R_0805_2012Metric_Pad1.20x1.40mm_HandSolder | Auto-extracted from KiCad PCB; verify against schematic before ordering
1 | C18 | 10u | Capacitor_SMD:C_0805_2012Metric_Pad1.18x1.45mm_HandSolder | Auto-extracted from KiCad PCB; verify against schematic before ordering
2 | R10, R27 | 1k | Resistor_SMD:R_0805_2012Metric_Pad1.20x1.40mm_HandSolder | Auto-extracted from KiCad PCB; verify against schematic before ordering
2 | C16, C17 | 1u | Capacitor_SMD:C_0805_2012Metric_Pad1.18x1.45mm_HandSolder | Auto-extracted from KiCad PCB; verify against schematic before ordering
1 | C14 | 22u | Capacitor_SMD:C_0805_2012Metric_Pad1.18x1.45mm_HandSolder | Auto-extracted from KiCad PCB; verify against schematic before ordering
1 | R25 | 300k | Resistor_SMD:R_0805_2012Metric_Pad1.20x1.40mm_HandSolder | Auto-extracted from KiCad PCB; verify against schematic before ordering
1 | R11 | 3k | Resistor_SMD:R_0805_2012Metric_Pad1.20x1.40mm_HandSolder | Auto-extracted from KiCad PCB; verify against schematic before ordering
1 | C19 | 4.7u | Capacitor_SMD:C_0805_2012Metric_Pad1.18x1.45mm_HandSolder | Auto-extracted from KiCad PCB; verify against schematic before ordering
1 | R26 | 56k | Resistor_SMD:R_0805_2012Metric_Pad1.20x1.40mm_HandSolder | Auto-extracted from KiCad PCB; verify against schematic before ordering
2 | J2, J3 | Conn_01x13_Pin | Library-kicad:13-conn-smd-dual | Auto-extracted from KiCad PCB; verify against schematic before ordering
1 | U4 | ESP32-WROOM-32UE | RF_Module:ESP32-WROOM-32UE | Auto-extracted from KiCad PCB; verify against schematic before ordering
2 | Onboard1, Outer1 | LED | LED_SMD:LED_0805_2012Metric_Pad1.15x1.40mm_HandSolder | Auto-extracted from KiCad PCB; verify against schematic before ordering
1 | NCP1 | NCP186AMX330TAG | Library-kicad:XDFN-8, 1.6 × 1.2 mm, 0.4 mm pitch | Auto-extracted from KiCad PCB; verify against schematic before ordering
2 | SW10, SW9 | SW_Push | Button_Switch_SMD:SW_SPST_CK_KXT3 | Auto-extracted from KiCad PCB; verify against schematic before ordering
1 | J1 | TC2030 | Connector_PinHeader_1.27mm:PinHeader_2x03_P1.27mm_Vertical | Auto-extracted from KiCad PCB; verify against schematic before ordering

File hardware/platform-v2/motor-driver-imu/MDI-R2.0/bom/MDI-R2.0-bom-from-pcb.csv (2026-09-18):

Quantity | References | Value / Part | Footprint | Source
1 | C21 | 0.1u | Capacitor_SMD:C_0805_2012Metric_Pad1.18x1.45mm_HandSolder | Auto-extracted from KiCad PCB; verify against schematic before ordering
4 | C4, C7, C8, C9 | 0.1uF | Capacitor_SMD:C_0805_2012Metric_Pad1.18x1.45mm_HandSolder | Auto-extracted from KiCad PCB; verify against schematic before ordering
2 | C27, C28 | 100n | Capacitor_SMD:C_0805_2012Metric_Pad1.18x1.45mm_HandSolder | Auto-extracted from KiCad PCB; verify against schematic before ordering
1 | C26 | 100u | Capacitor_SMD:C_1206_3216Metric_Pad1.33x1.80mm_HandSolder | Auto-extracted from KiCad PCB; verify against schematic before ordering
6 | R12, R13, R14, R18, R3, R4 | 10k | Resistor_SMD:R_0603_1608Metric_Pad0.98x0.95mm_HandSolder | Auto-extracted from KiCad PCB; verify against schematic before ordering
1 | C25 | 10u | Capacitor_SMD:C_0805_2012Metric_Pad1.18x1.45mm_HandSolder | Auto-extracted from KiCad PCB; verify against schematic before ordering
2 | R15, R16 | 4.7k | Resistor_SMD:R_0603_1608Metric_Pad0.98x0.95mm_HandSolder | Auto-extracted from KiCad PCB; verify against schematic before ordering
1 | C2 | 4.7uF | Capacitor_SMD:C_0805_2012Metric_Pad1.18x1.45mm_HandSolder | Auto-extracted from KiCad PCB; verify against schematic before ordering
2 | R23, R24 | 47 | Resistor_SMD:R_1206_3216Metric_Pad1.30x1.75mm_HandSolder | Auto-extracted from KiCad PCB; verify against schematic before ordering
1 | BMO1 | BNO086 | Package_LGA:LGA-28_5.2x3.8mm_P0.5mm | Auto-extracted from KiCad PCB; verify against schematic before ordering
2 | J6, J7 | BNO_BOOT_Test_pin | Connector_Wire:SolderWirePad_1x01_SMD_1x2mm | Auto-extracted from KiCad PCB; verify against schematic before ordering
1 | J1 | Conn_01x13_Pin | Library-kicad:13-conn-smd-dual | Auto-extracted from KiCad PCB; verify against schematic before ordering
3 | J4, J5, J8 | Screw_Terminal_01x02 | Library-kicad:power pad dual | Auto-extracted from KiCad PCB; verify against schematic before ordering
1 | TC78H651FNG1 | TC78H651FGN,EL | Package_SO:TSSOP-16_4.4x5mm_P0.65mm | Auto-extracted from KiCad PCB; verify against schematic before ordering

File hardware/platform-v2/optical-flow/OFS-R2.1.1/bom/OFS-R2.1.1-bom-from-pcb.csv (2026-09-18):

Quantity | References | Value / Part | Footprint | Source
3 | C2, C4, C5 | 100nF | Capacitor_SMD:C_0603_1608Metric | Auto-extracted from KiCad PCB; verify against schematic before ordering
1 | R1 | 10K | Resistor_SMD:R_0603_1608Metric | Auto-extracted from KiCad PCB; verify against schematic before ordering
3 | C3, C6, C8 | 10uF | Capacitor_SMD:C_0603_1608Metric | Auto-extracted from KiCad PCB; verify against schematic before ordering
2 | C11, C9 | 1uF | Capacitor_SMD:C_0603_1608Metric | Auto-extracted from KiCad PCB; verify against schematic before ordering
1 | C10 | 22nF | Capacitor_SMD:C_0603_1608Metric | Auto-extracted from KiCad PCB; verify against schematic before ordering
1 | C7 | 22uF | Capacitor_SMD:C_0805_2012Metric | Auto-extracted from KiCad PCB; verify against schematic before ordering
1 | R3 | 2M | Resistor_SMD:R_0603_1608Metric | Auto-extracted from KiCad PCB; verify against schematic before ordering
1 | R2 | 4.7 | Resistor_SMD:R_0603_1608Metric | Auto-extracted from KiCad PCB; verify against schematic before ordering
1 | C1 | 4.7uF | Capacitor_SMD:C_0603_1608Metric | Auto-extracted from KiCad PCB; verify against schematic before ordering
1 | U3 | AP2127K-1.8 | Package_TO_SOT_SMD:SOT-23-5 | Auto-extracted from KiCad PCB; verify against schematic before ordering
1 | J3 | Conn_01x07_Pin | Library-kicad:7 pin smd conn 2.54 | Auto-extracted from KiCad PCB; verify against schematic before ordering
1 | U2 | PAW3395 | Library-kicad:PAW3395 | Auto-extracted from KiCad PCB; verify against schematic before ordering

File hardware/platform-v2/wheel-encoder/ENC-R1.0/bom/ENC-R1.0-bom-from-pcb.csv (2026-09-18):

Quantity | References | Value / Part | Footprint | Source
1 | C2 | 100n | Capacitor_SMD:C_0603_1608Metric | Auto-extracted from KiCad PCB; verify against schematic before ordering
1 | C1 | 1u | Capacitor_SMD:C_0603_1608Metric | Auto-extracted from KiCad PCB; verify against schematic before ordering
2 | J1, J2 | Conn_01x07_Socket | Library-kicad:7 pin smd conn 2.54 | Auto-extracted from KiCad PCB; verify against schematic before ordering
1 | U1 | MA730 | Package_DFN_QFN:QFN-16-1EP_3x3mm_P0.5mm_EP1.75x1.75mm | Auto-extracted from KiCad PCB; verify against schematic before ordering

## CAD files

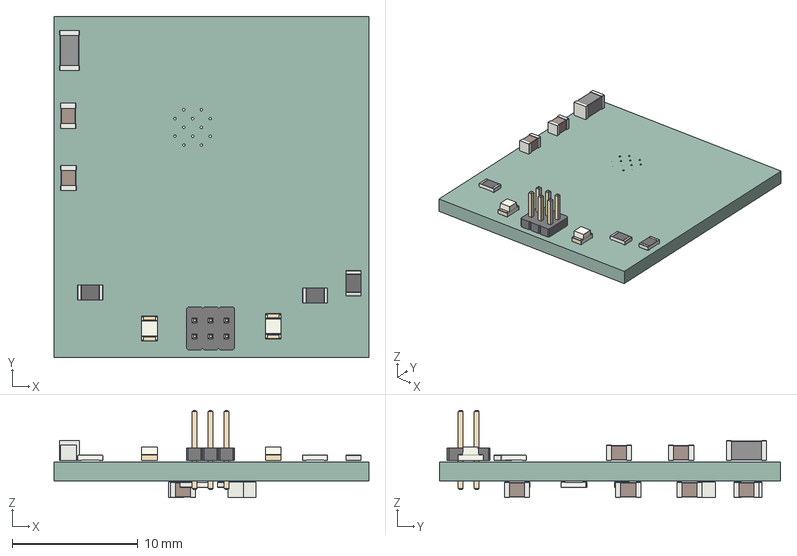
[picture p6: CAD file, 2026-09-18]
hardware/platform-v2/mainboard/MB-R2.1/source/v2 motherboard step.step
25.0 x 27.1 x 6.93 mm
C_0805_2012Metric x 8
PinHeader_2x03_P1.27mm_Vertical
R_0805_2012Metric x 7
L_1206_3216Metric
LED_0805_2012Metric x 2
V2-4 piece modular vertical_PCB

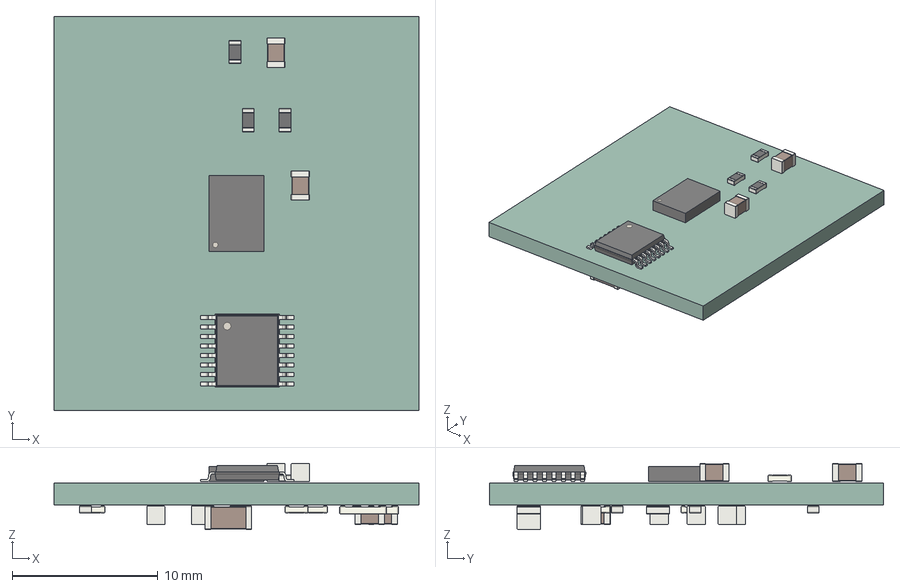
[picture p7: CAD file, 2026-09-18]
hardware/platform-v2/motor-driver-imu/MDI-R2.0/source/v2 motor driver.step
25.0 x 27.0 x 4.53 mm
R_0603_1608Metric x 8
C_0805_2012Metric x 9
TSSOP-16_4.4x5mm_P0.65mm
LGA-28_5.2x3.8mm_P0.5mm
R_1206_3216Metric x 2
C_1206_3216Metric
motor drivers_PCB

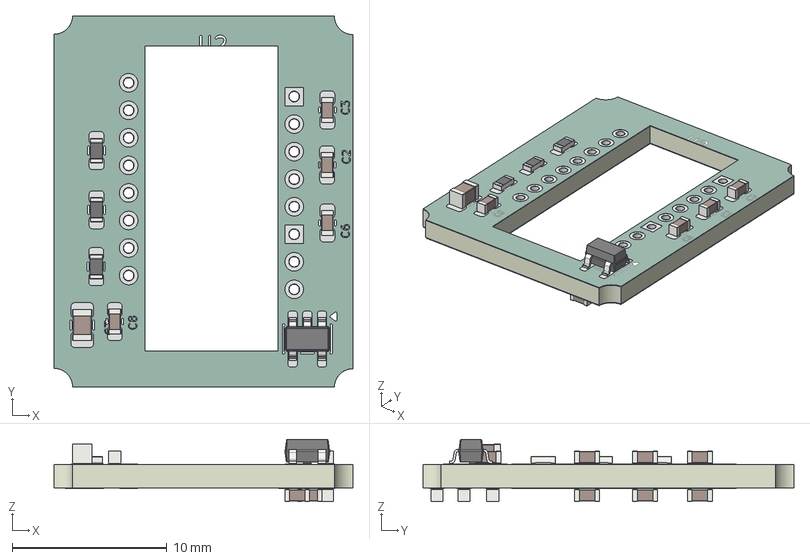
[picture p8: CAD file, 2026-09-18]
hardware/platform-v2/optical-flow/OFS-R2.1.1/source/3d/v2.step
19.3 x 24.0 x 4.03 mm
C_0603_1608Metric x 10
SOT-23-5
R_0603_1608Metric x 3
C_0805_2012Metric
optical tracking sensor paw 3395_pad
optical tracking sensor paw 3395_silkscreen x 2
optical tracking sensor paw 3395_soldermask x 2
optical tracking sensor paw 3395_PCB

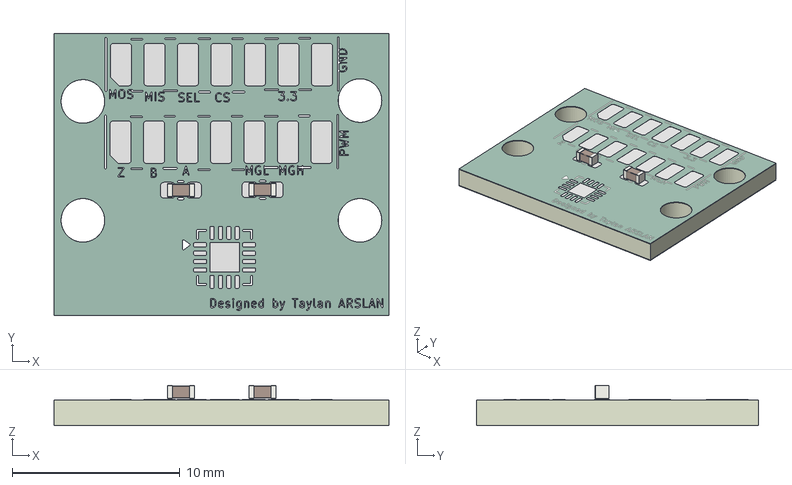
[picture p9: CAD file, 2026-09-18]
hardware/platform-v2/wheel-encoder/ENC-R1.0/source/HAL encoder circuit v1.step
20.0 x 16.8 x 2.47 mm
C_0603_1608Metric x 2
Wheel-Encoder_pad
Wheel-Encoder_silkscreen x 2
Wheel-Encoder_soldermask x 2
Wheel-Encoder_PCB

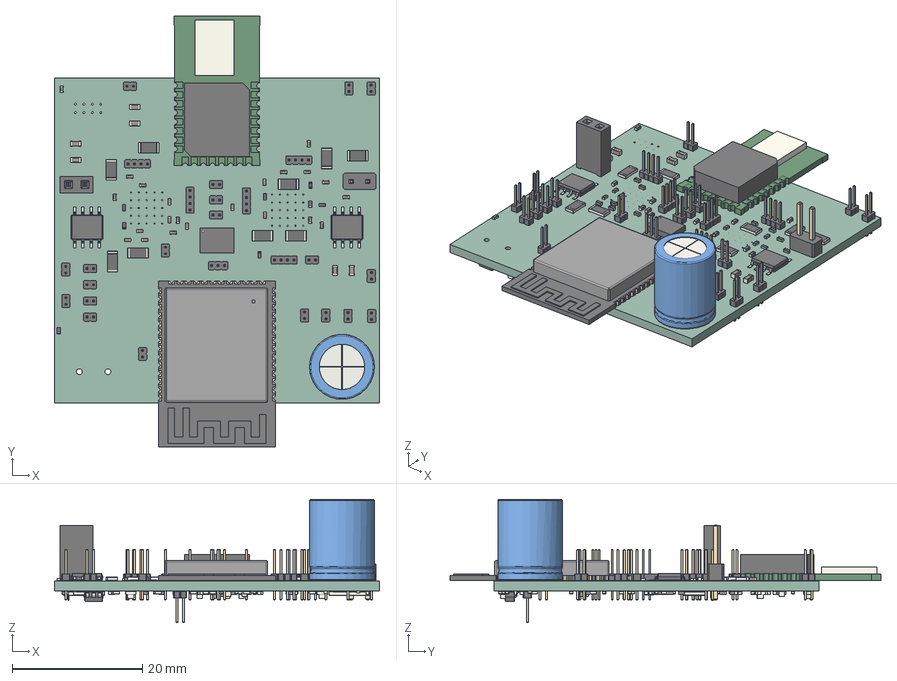
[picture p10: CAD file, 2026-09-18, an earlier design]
hardware/platform-v1/INT-R1.0.1/source/pcb.step
50.0 x 66.2 x 19.0 mm
C_0603_1608Metric x 9
PinHeader_1x02_P1.00mm_Vertical x 21
R_1206_3216Metric x 10
PinHeader_1x04_P1.00mm_Vertical x 5
HSOP-8-1EP_3.9x4.9mm_P1.27mm_EP2.41x3.1mm x 2
C_Radial_D10.0mm_H12.5mm_P5.00mm
PinHeader_1x03_P1.00mm_Vertical
C_0402_1005Metric x 50
R_0402_1005Metric x 42
DWM1000
ESP32-S3-WROOM-1
PinHeader_2x01_P2.54mm_Vertical
PinSocket_2x01_P2.54mm_Vertical
LGA-28_5.2x3.8mm_P0.5mm
LED_0603_1608Metric x 6
R_0603_1608Metric x 4
SOT-23-6
R_2512_6332Metric x 2
V1_PCB

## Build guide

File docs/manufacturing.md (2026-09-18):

# Manufacturing and assembly guide

## Before ordering anything

1. Read `VERSIONING.md`.
2. Use only the `current/` fabrication package for the board you intend to build.
3. Open the corresponding KiCad source and compare the generated Gerbers against the source revision.
4. Check footprints, connector orientation, board stack-up, copper layers, drill files, and outline in the fabricator viewer.
5. Re-check the BOM against current component datasheets and stock. The included CSV BOMs are extraction aids, not purchasing authority.

## Current fabrication targets

| Board | Current fab revision | Layers | Approx. outline |
|---|---|---:|---:|
| Platform V1 integrated PCB | INT-R1.0.1 | 8 | 50 × 50 mm |
| V2 mainboard | MB-R2.1 | 4 | 25 × 27.1 mm |
| V2 motor/IMU | MDI-R2.0 | 4 | 25 × 27 mm |
| V2 PAW3395 optical flow | OFS-R2.1.1 | 2 | 19.3 × 24.0 mm |
| V2 MA730 encoder | ENC-R1.0 | 2 | 20 × 16.8 mm |

## Assembly priorities

### Mainboard

- Confirm 3.3 V regulator orientation and passive values before fitting the ESP32.
- Verify 3.3 V rail resistance to ground before first power-up.
- Bring up the board from a current-limited bench supply when possible.
- Verify EN/BOOT/programming access before connecting daughterboards.

### Motor/IMU board

- Confirm the TC78H651 package orientation and motor-output pads.
- Check the BNO086 orientation relative to the carrier coordinate frame and record the convention in software.
- Power logic and motor rails cautiously; test each H-bridge at low duty cycle with the carrier lifted off the table.

### PAW3395 optical-flow board

This is currently the only V2 board not experimentally validated, so it deserves the most cautious bring-up.

- Check the 1.8 V rail before installing/energising the PAW3395 if the assembly process allows.
- Verify sensor orientation and the optical lens/mechanical height.
- Confirm SPI idle states and nCS behaviour before attempting motion reads.
- The schematic specifies **R3 = 2 MΩ**; do not silently substitute a different value in published builds.
- Treat optical height, surface texture, and lens selection as part of the sensor system, not just PCB assembly.

> **Image placeholder — PAW3395 assembly:** I will add a close-up showing the sensor/lens spacing and the underside mounting here.

### MA730 encoder

- The magnetic target, air gap, centring, and alignment are as important as the PCB.
- Validate angle continuity through a full revolution before using data for odometry.
- Record the exact magnet geometry used in experimental data.

> **Image placeholder — encoder magnet:** I will add the final magnet and wheel/shaft arrangement here after mechanical integration.

## Power and batteries

The repository does not include a certified charger or battery-management product. Use an appropriate protected cell/pack and charger for the selected 1S LiPo system. Never treat the PCB as a substitute for battery protection.

## KiCad-generated local files intentionally removed

The public repository excludes `.history/`, `*-backups/`, `*.kicad_prl`, and lock files. These are editor state/backups rather than reproducible design inputs and would make the project history unnecessarily confusing.

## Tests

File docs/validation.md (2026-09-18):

# Validation status and test plan

## Current evidence level

| Item | Current status | Meaning |
|---|---|---|
| Platform V1 integrated PCB | **Validated** | Historical board has been built/bench checked; retained as superseded hardware |
| MB-R2.1 mainboard | **Validated** | Controller/power board has been bench validated |
| MDI-R2.0 motor/IMU board | **Validated** | Board has been bench validated |
| ENC-R1.0 wheel encoder | **Validated** | Board has been bench validated |
| OFS-R2.1.1 PAW3395 board | **Unvalidated** | Design/fabrication files complete; experimental verification still required |
| Full Platform V2 carrier | **Integration in progress** | Design finished; manufacturing/assembly semi-finished and awaiting parts |
| Sensor-fusion autonomy | **Not yet validated** | Firmware/software still to be developed |
| Autonomous optical alignment | **Not yet validated** | Experimental goal, not a current result |

“Validated” here means practical board-level bring-up/bench validation. It does **not** mean that final localisation accuracy, drift, lifetime, EMC, temperature range, or optical-alignment performance has been fully characterised.

## Recommended board-level tests

### MB-R2.1

- input current at idle;
- 3.3 V rail value and stability;
- boot/programming through TC2030;
- IO13 LED control;
- serial communication;
- header continuity and power-pin verification.

### MDI-R2.0

- H-bridge output polarity for all input states;
- PWM response under representative motor load;
- supply droop and thermal behaviour;
- BNO086 identity/communication;
- interrupt/reset behaviour;
- coordinate-frame verification.

### OFS-R2.1.1

- 1.8 V regulation;
- SPI identity/init sequence;
- MOTION interrupt;
- raw x/y counts under calibrated linear displacement;
- sensitivity versus surface texture, speed, height, and orientation;
- repeatability over repeated traverses.

### ENC-R1.0

- SPI angle continuity through 0/360°;
- repeatability at fixed angular positions;
- magnetic field status (MGL/MGH);
- A/B/Z output validity if used;
- error versus magnet offset and air gap.

## System-level experiments

### 1. Straight-line motion calibration

Command several distances in both directions and compare:

- wheel-derived displacement;
- PAW3395 displacement;
- overhead-camera ground truth;
- fused estimate.

### 2. Rotation calibration

Command repeated yaw changes and compare encoder/kinematic prediction, IMU yaw, visual ground truth, and fused yaw.

### 3. Return-to-pose repeatability

Move away from a reference pose and return to it repeatedly. Report mean error, standard deviation, radial error distribution, and yaw error rather than a single “accuracy” number.

### 4. Static drift

Keep the carrier stationary for a defined duration and record each estimator. Distinguish sensor noise, estimator drift, and actual mechanical motion.

### 5. Slip/recovery test

Deliberately perturb a wheel or move the carrier without corresponding wheel rotation. Measure how quickly optical flow/global vision causes the estimator to recover.

### 6. Optical task

Define a simple measurable optical objective, e.g. beam centring or a polarisation/throughput measurement. Report initial error, convergence criterion, number of attempts, final error, and success rate.

## Data discipline

Raw data should never be overwritten by processed results. Store calibration parameters, board revisions, firmware commit, camera calibration, surface type, motor/battery configuration, and mechanical geometry with every run.

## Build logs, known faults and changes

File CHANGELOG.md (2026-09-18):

# Changelog / design lineage

This file records architectural changes rather than every KiCad edit.

## Platform V2 — current architecture (August–September 2026)

- Reworked the carrier into a modular architecture centred on an **ESP32-WROOM-32UE** mainboard.
- Replaced the V1 integrated motor/stepper approach with a dedicated **TC78H651** dual H-bridge board for low-speed DC gearmotors.
- Retained **BNO086** inertial sensing on the motor/IMU daughterboard.
- Added a dedicated **PAW3395** bottom-facing optical-flow board with local **1.8 V regulation**.
- Added a dedicated **MA730** magnetic wheel-angle encoder board.
- Removed UWB from the current core sensing architecture.
- Decoupled fine optomechanical alignment from the mobile-base electronics; the carrier now focuses on robust coarse transport/localisation while fine correction can be added as a separate optomechanical layer.
- Current hardware design completed; system manufacturing remains partially complete while parts arrive.

## Platform V1 — integrated architecture (July–August 2026)

- Developed a roughly **50 × 50 mm, 8-layer** integrated carrier PCB.
- Used **ESP32-S3-WROOM-1** as controller.
- Integrated **DWM3000 UWB** and **BNO086 IMU**.
- Included **TMC5041** stepper-control stages and **DRV8231** motor-driver stages.
- Provided the first hardware implementation of the autonomous-photonics carrier concept.
- Retained in the repository as a validated historical design and design-reference point.

## Legacy reference — before Platform V1

The `hardware/legacy-reference/` directory contains an earlier general-purpose ESP32 robot-controller design. It influenced later design choices but is **not** a version of the autonomous photonics carrier.

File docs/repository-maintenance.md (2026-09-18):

# Repository maintenance notes

## Public-source hygiene

The repository intentionally omits KiCad local history repositories, autosave backup folders, lock files, and personal project-local settings. Git history should be used for public revision tracking instead.

## Updating hardware

When a board changes:

1. increment that board's revision only;
2. do not create a new Platform generation unless the system architecture itself changes;
3. move the replaced fabrication package to `archive/`;
4. generate/update the board BOM CSV;
5. update `VERSIONING.md`, the board README, and `CHANGELOG.md`;
6. record validation status honestly;
7. update fabrication checksums.

## Image policy

Photographs should identify the board revision in the caption or filename when practical. Avoid using a photo of an older board next to a current fabrication link without clearly labelling it.

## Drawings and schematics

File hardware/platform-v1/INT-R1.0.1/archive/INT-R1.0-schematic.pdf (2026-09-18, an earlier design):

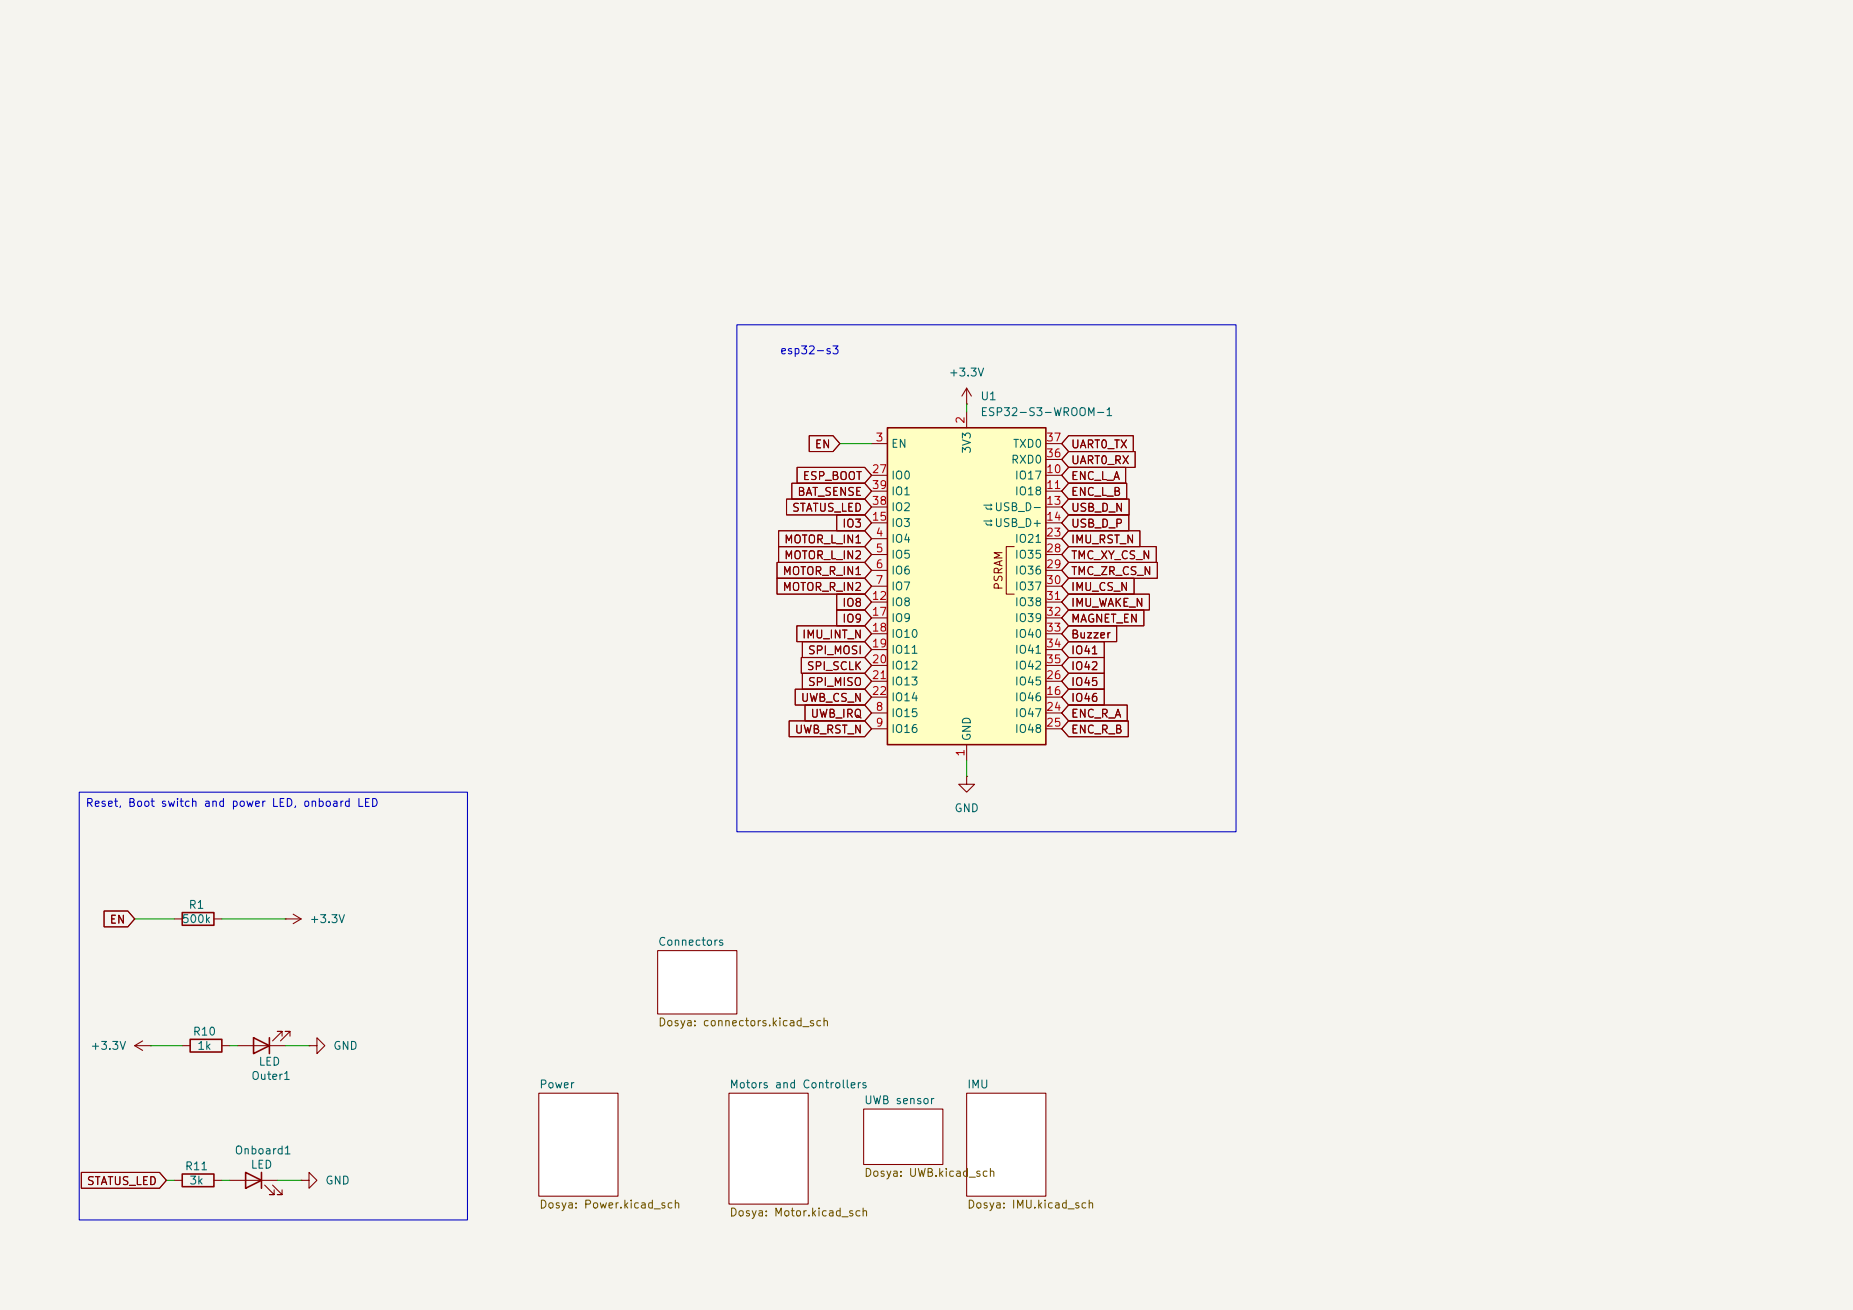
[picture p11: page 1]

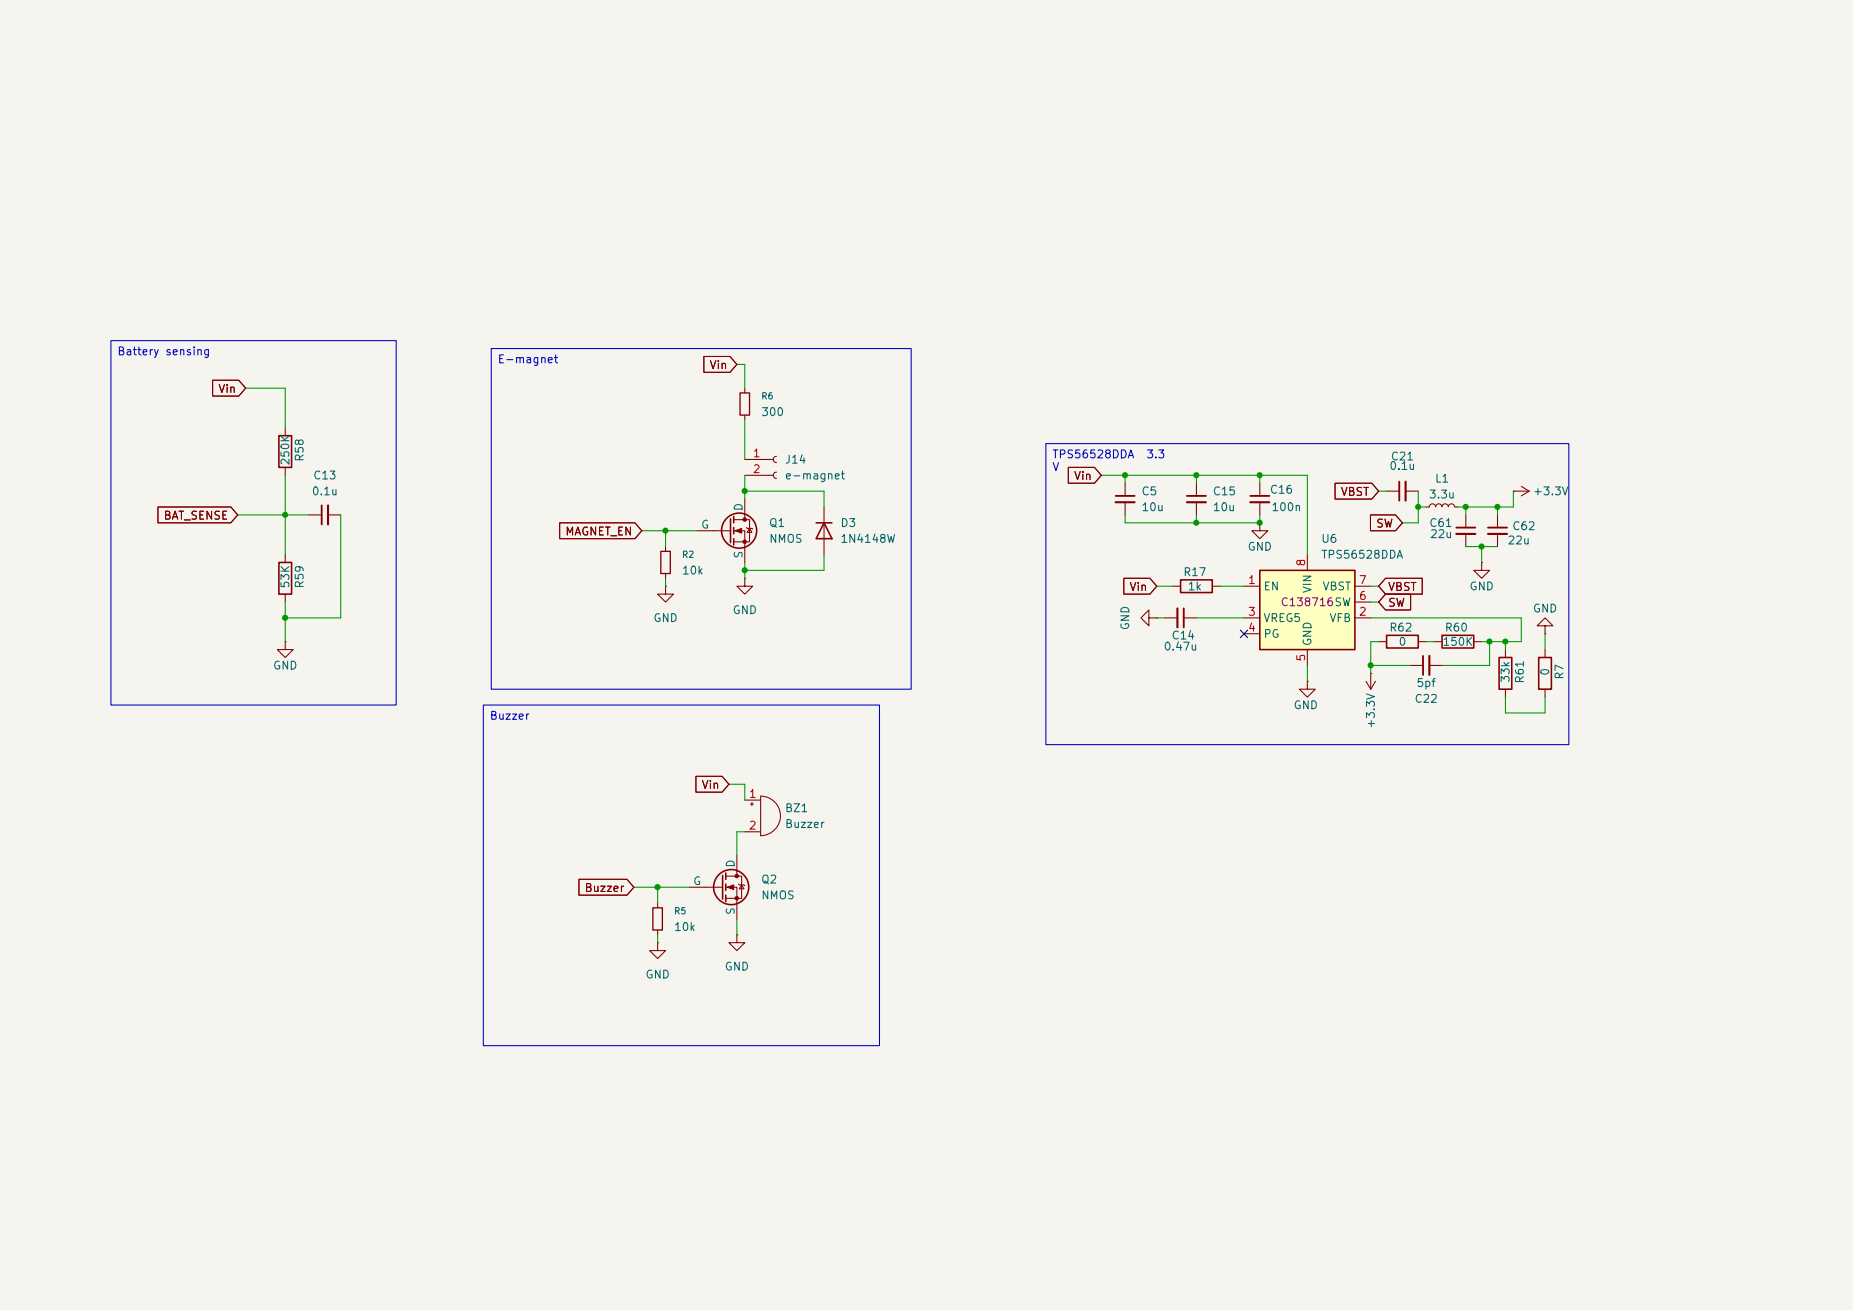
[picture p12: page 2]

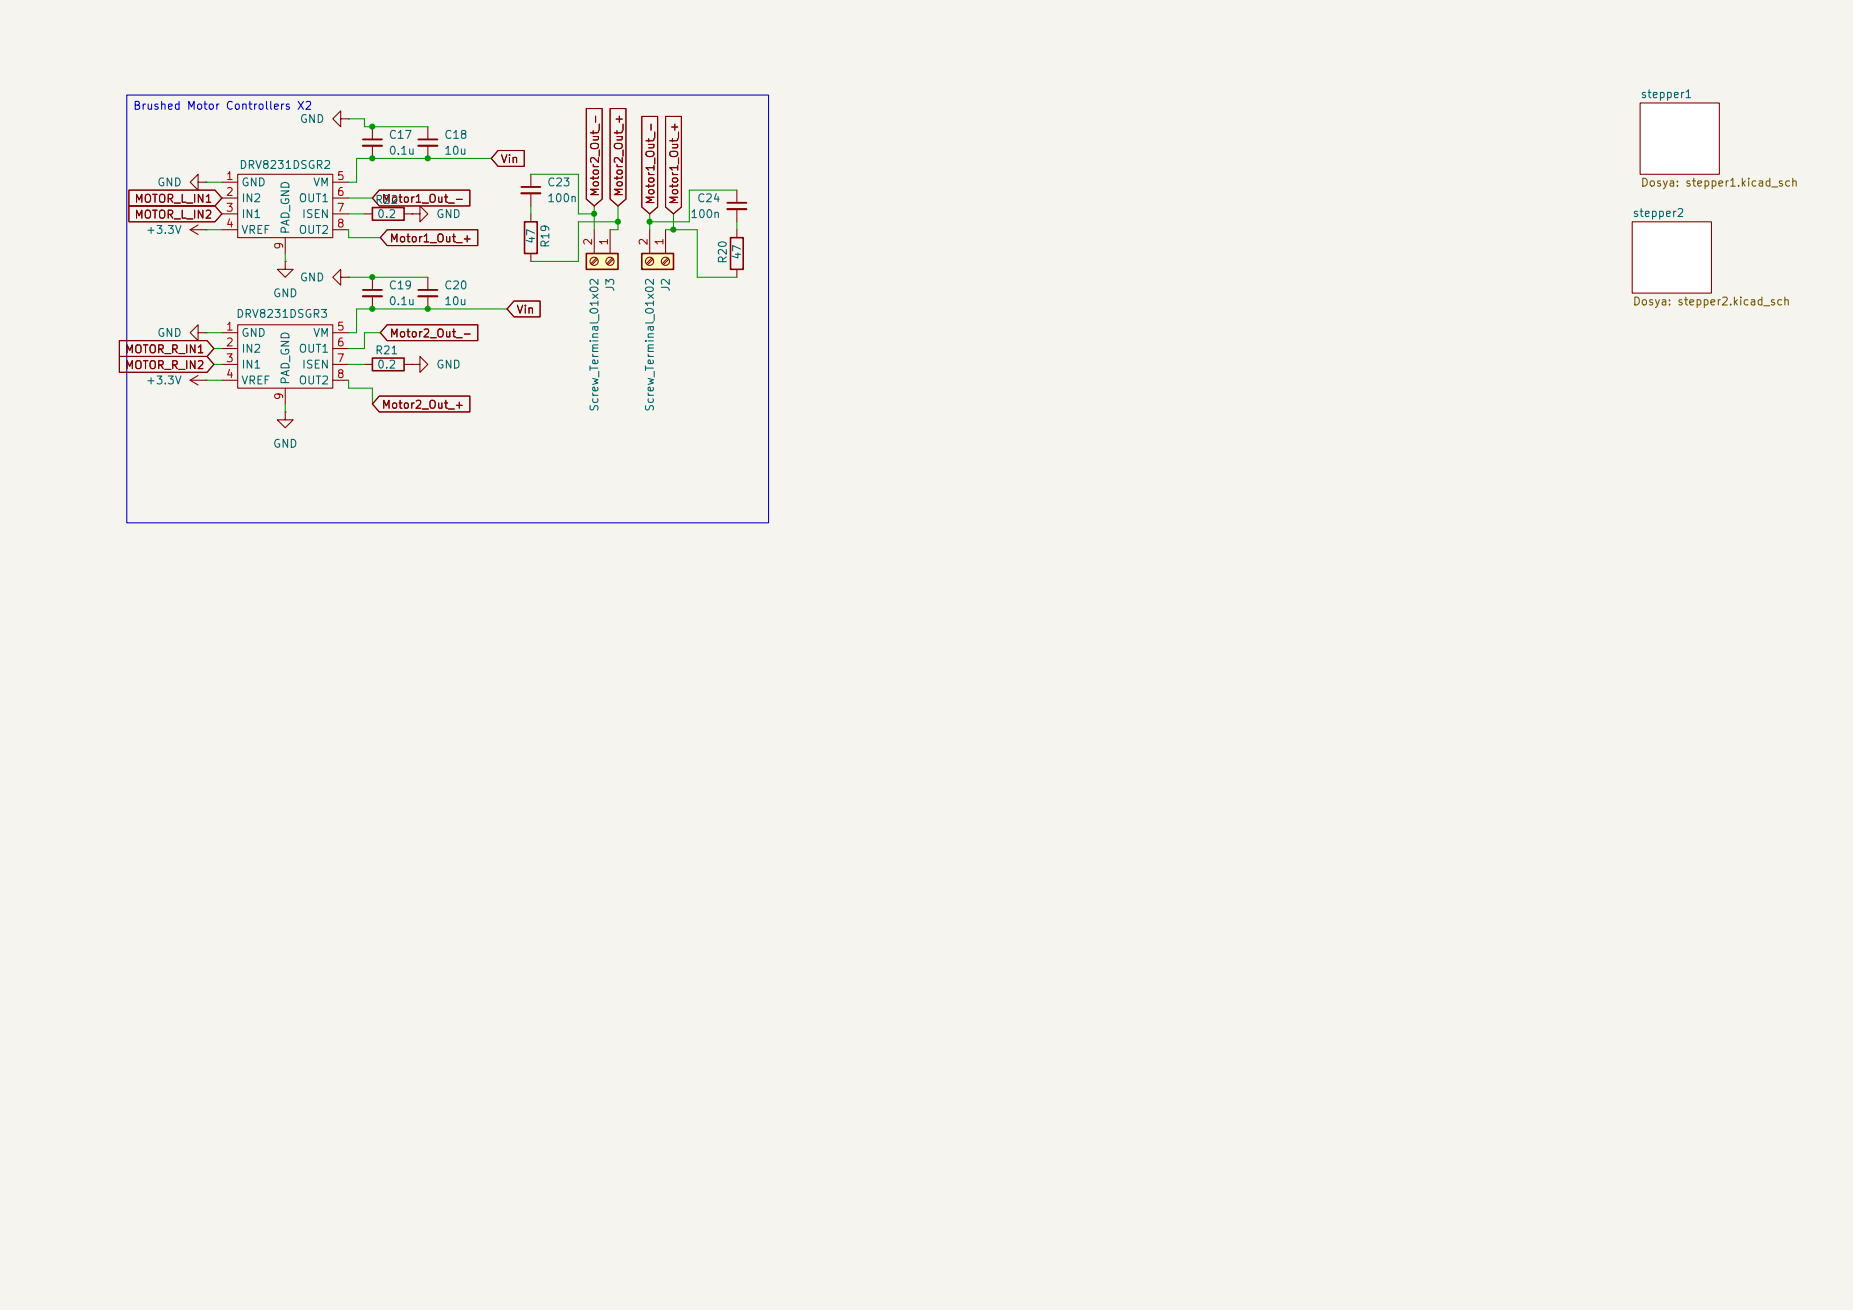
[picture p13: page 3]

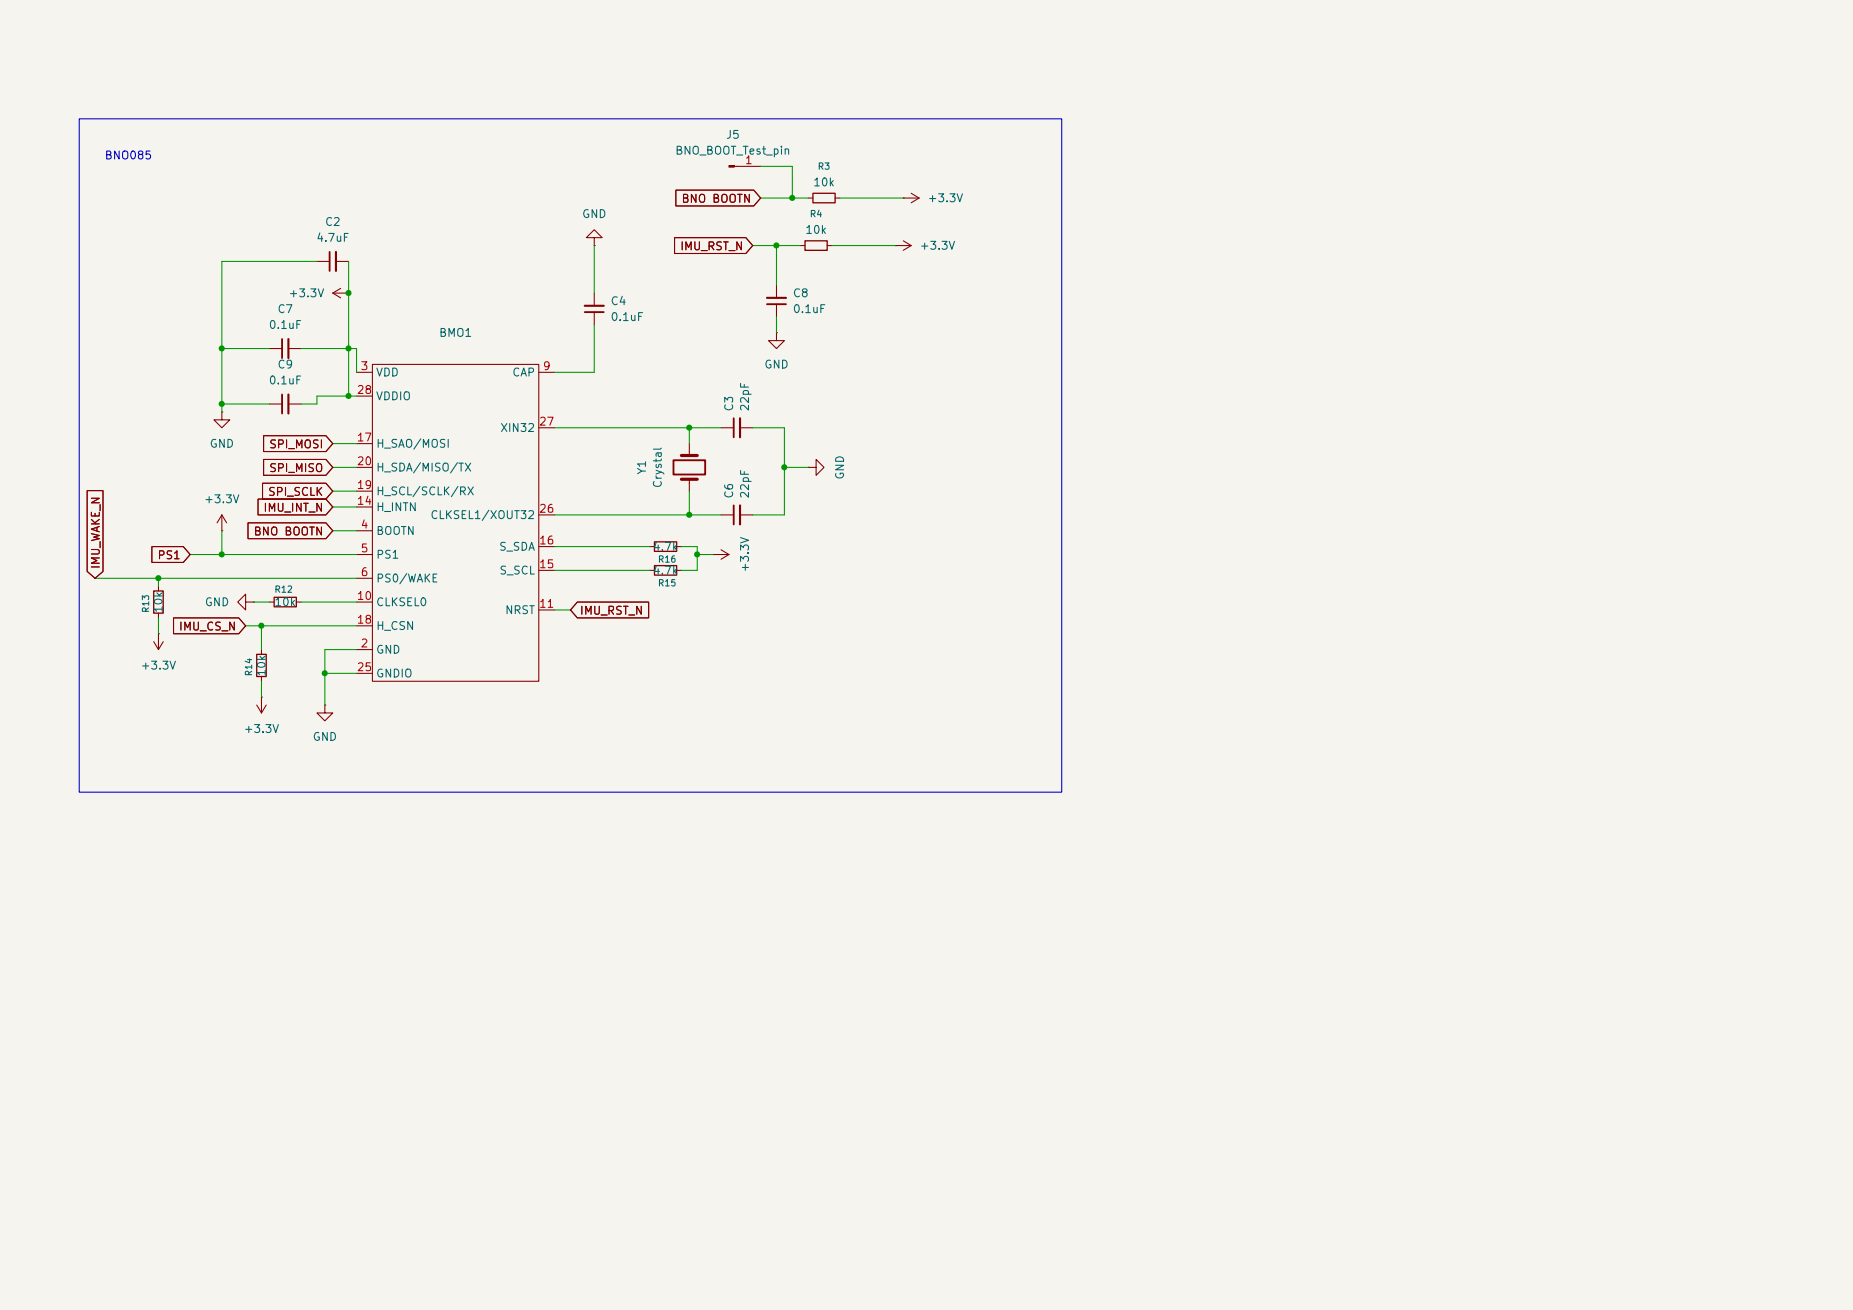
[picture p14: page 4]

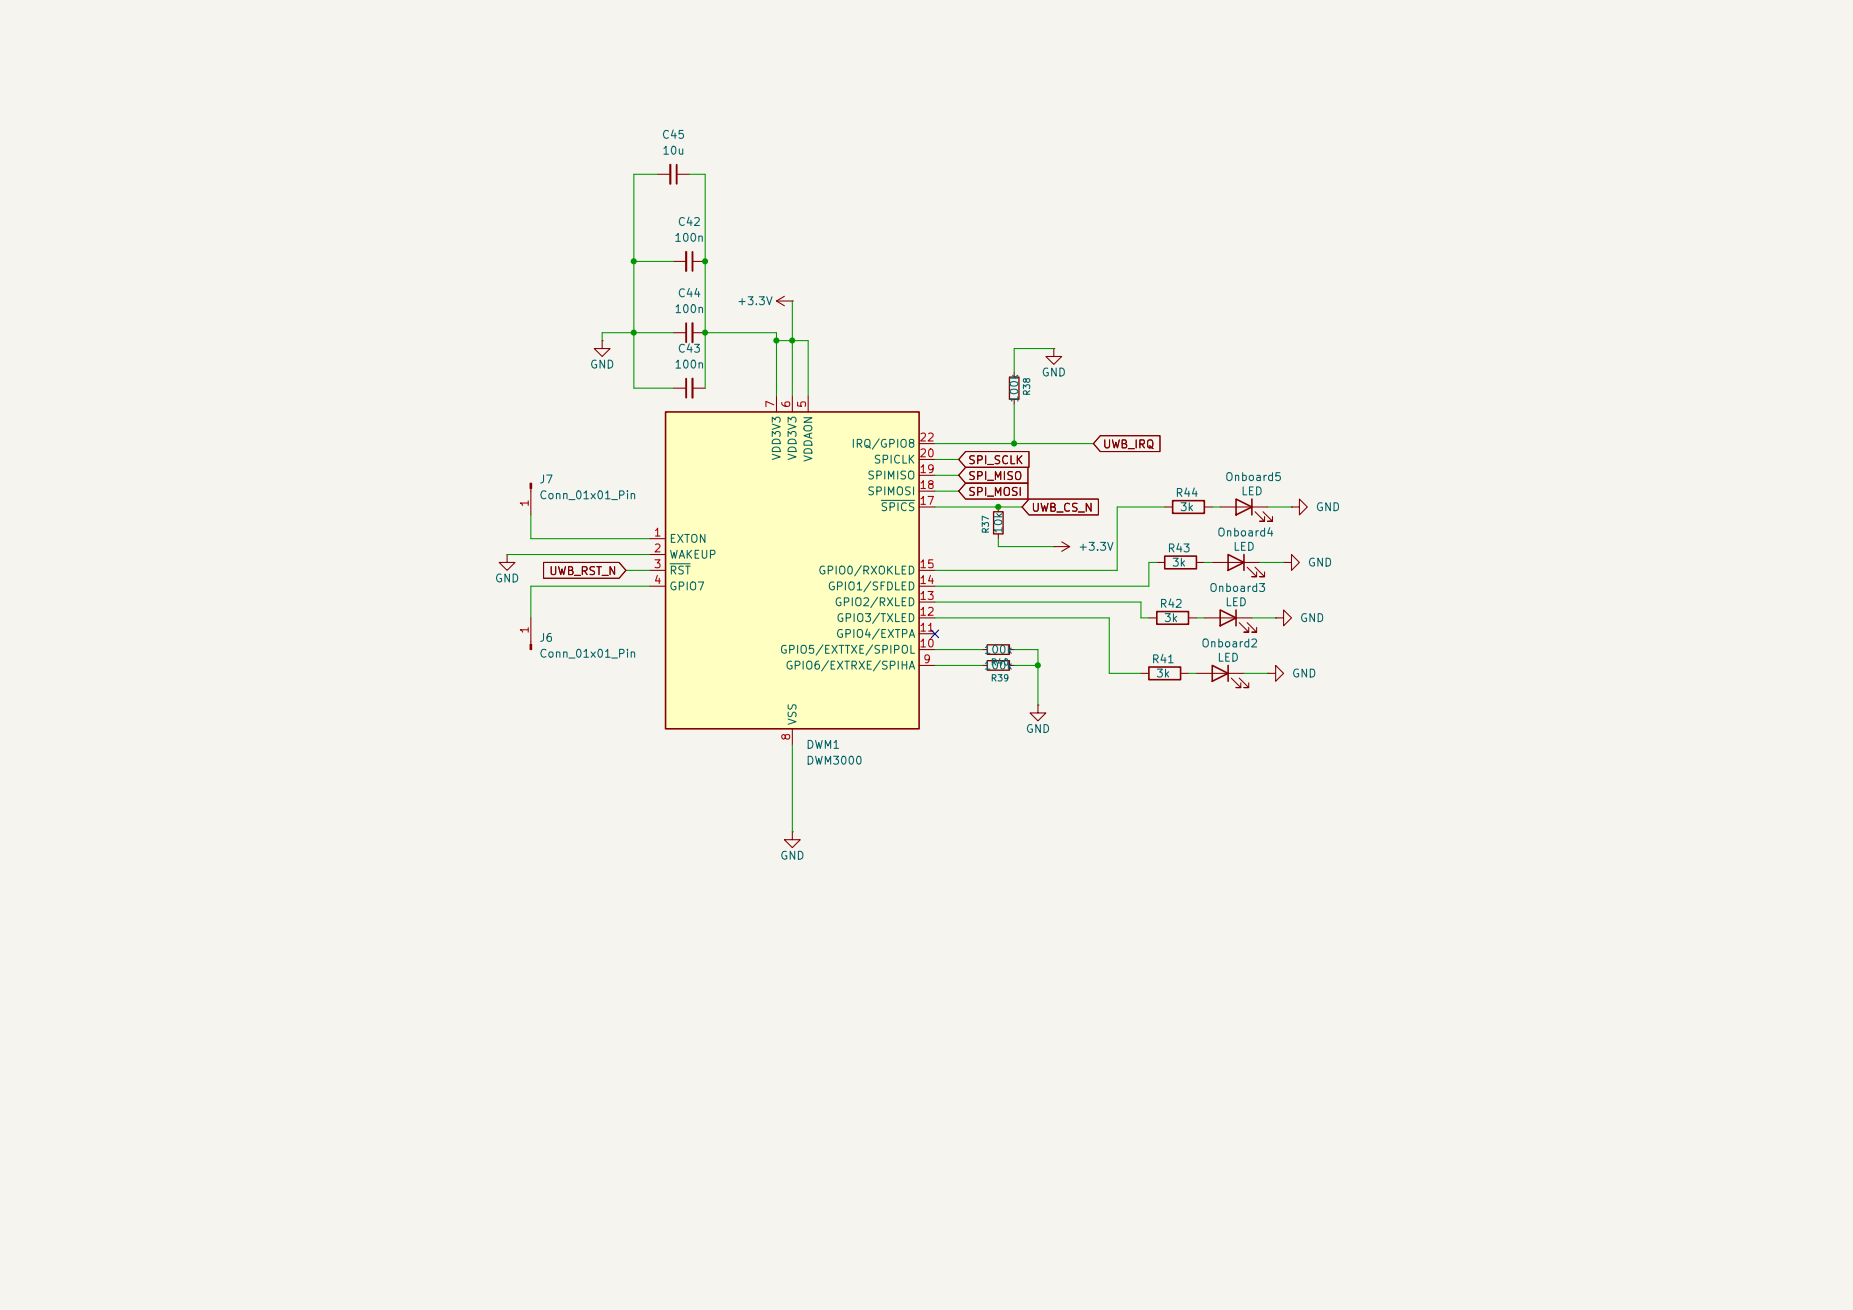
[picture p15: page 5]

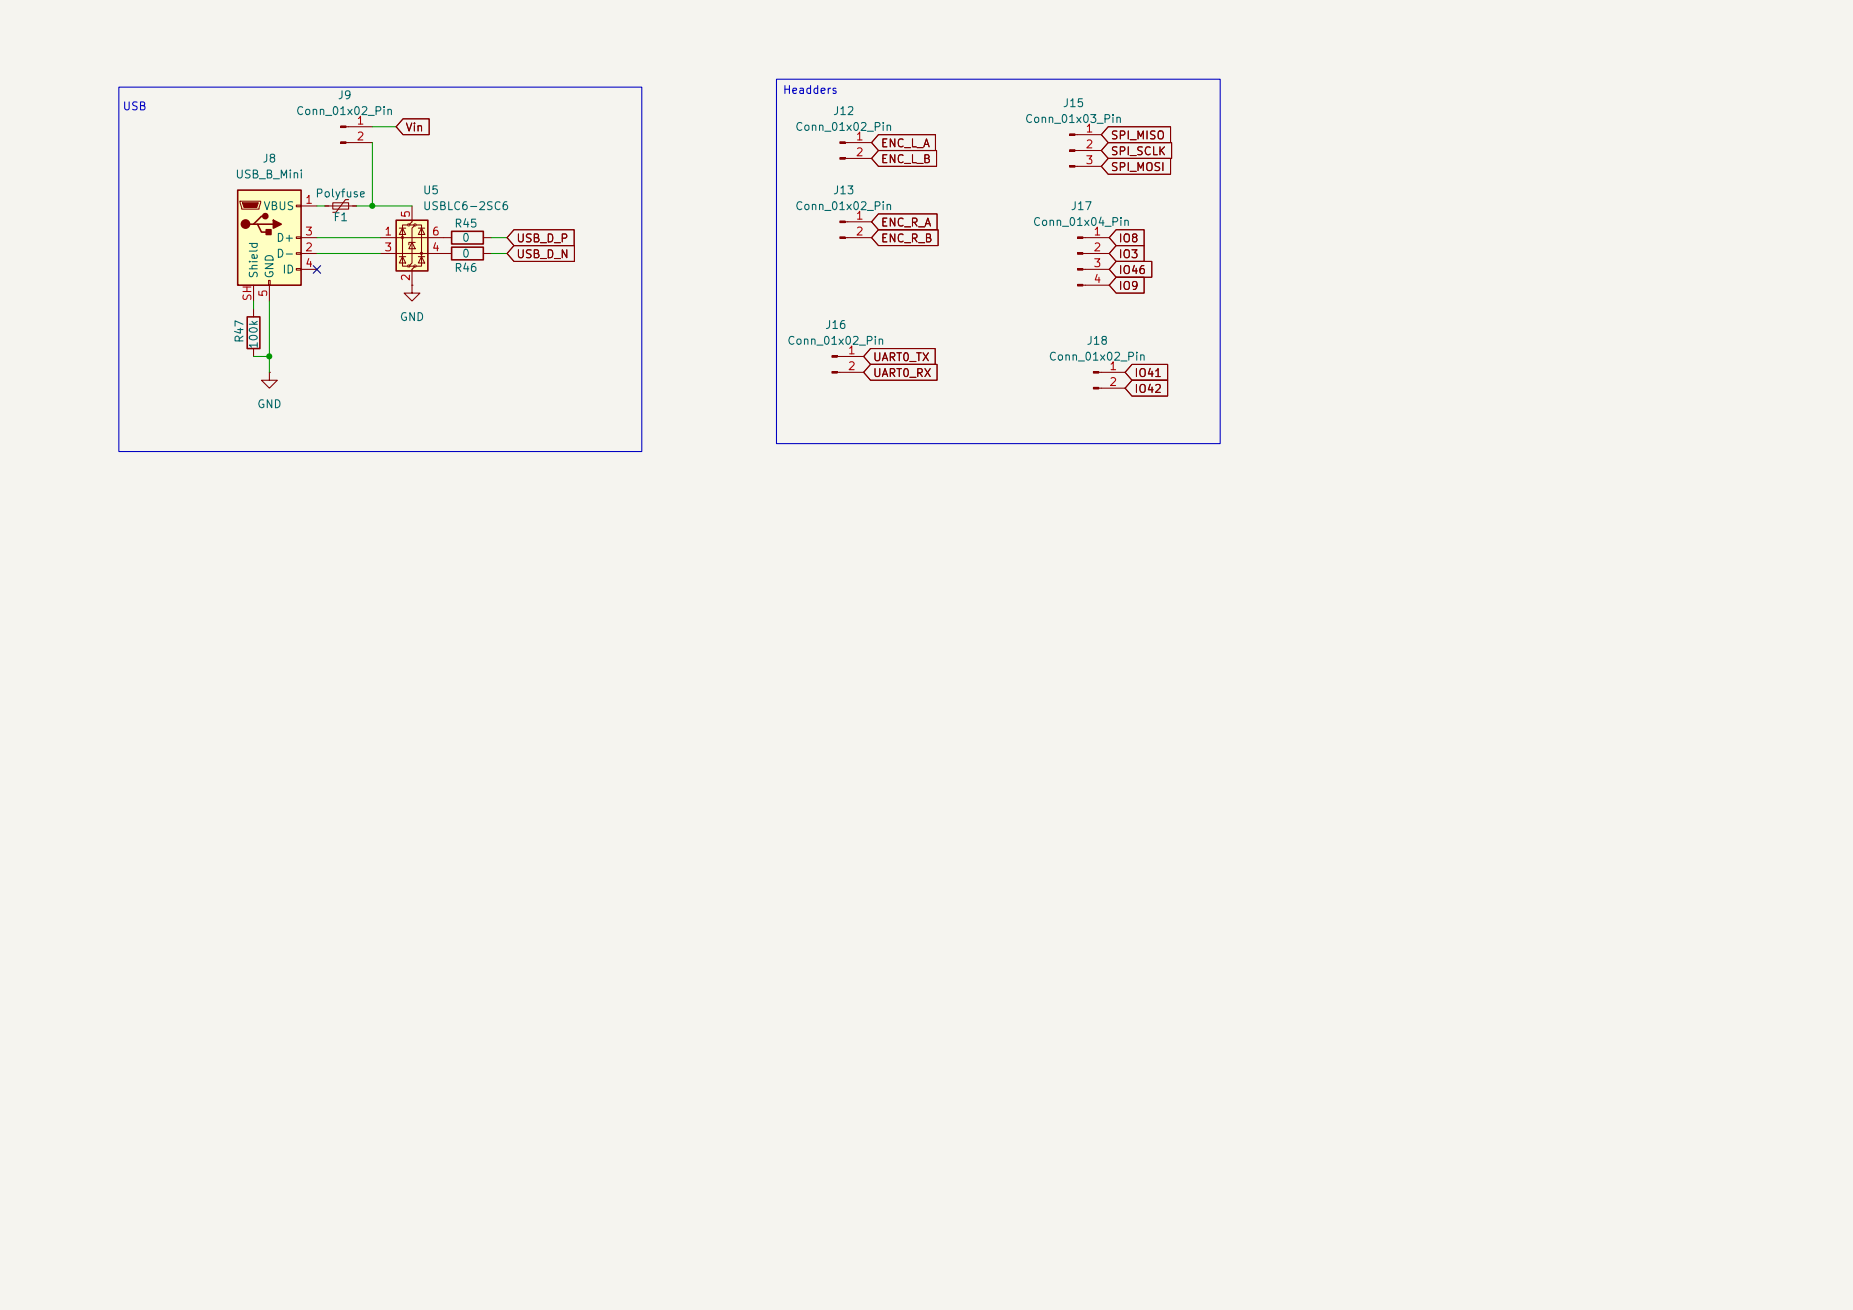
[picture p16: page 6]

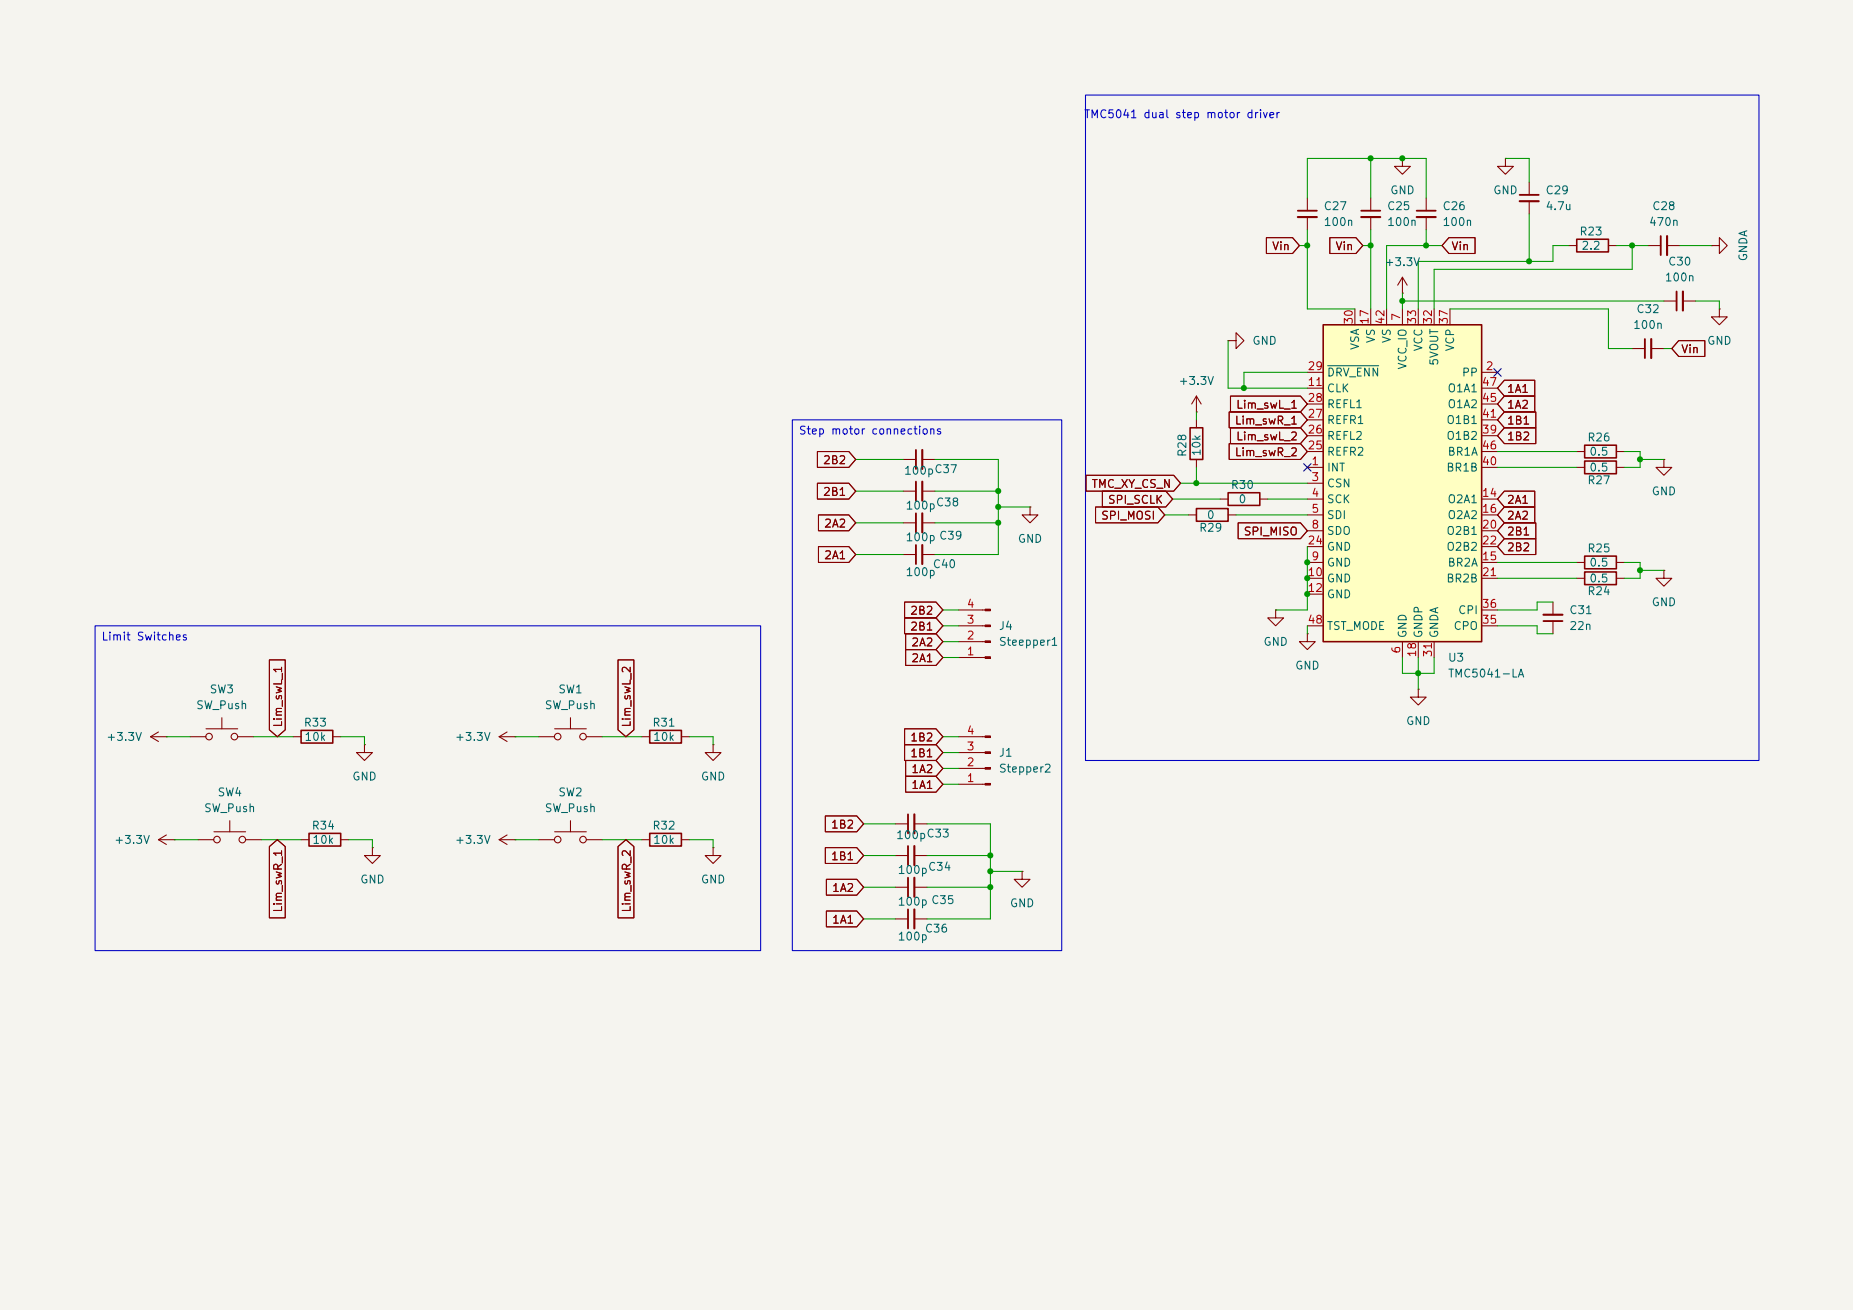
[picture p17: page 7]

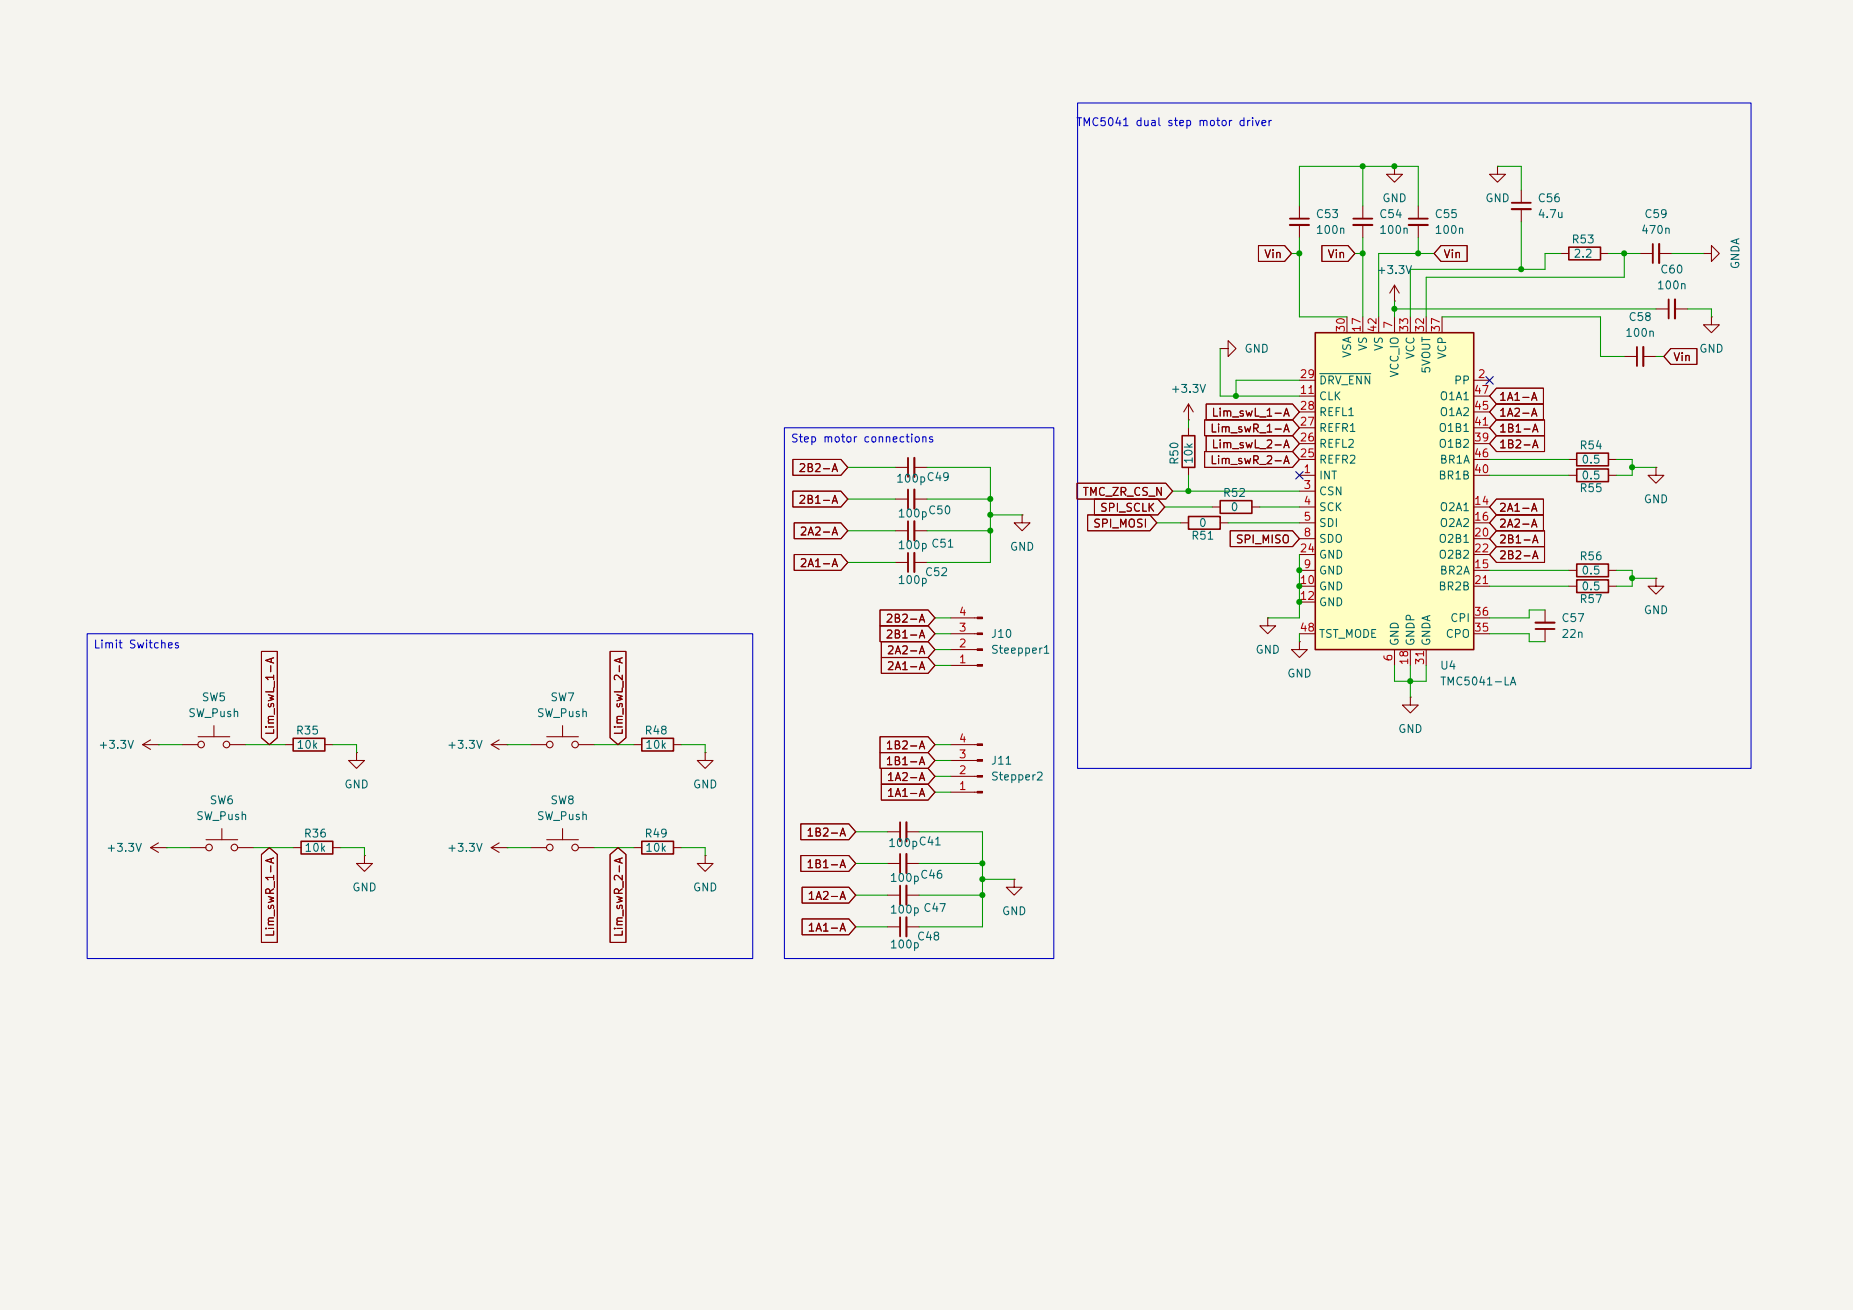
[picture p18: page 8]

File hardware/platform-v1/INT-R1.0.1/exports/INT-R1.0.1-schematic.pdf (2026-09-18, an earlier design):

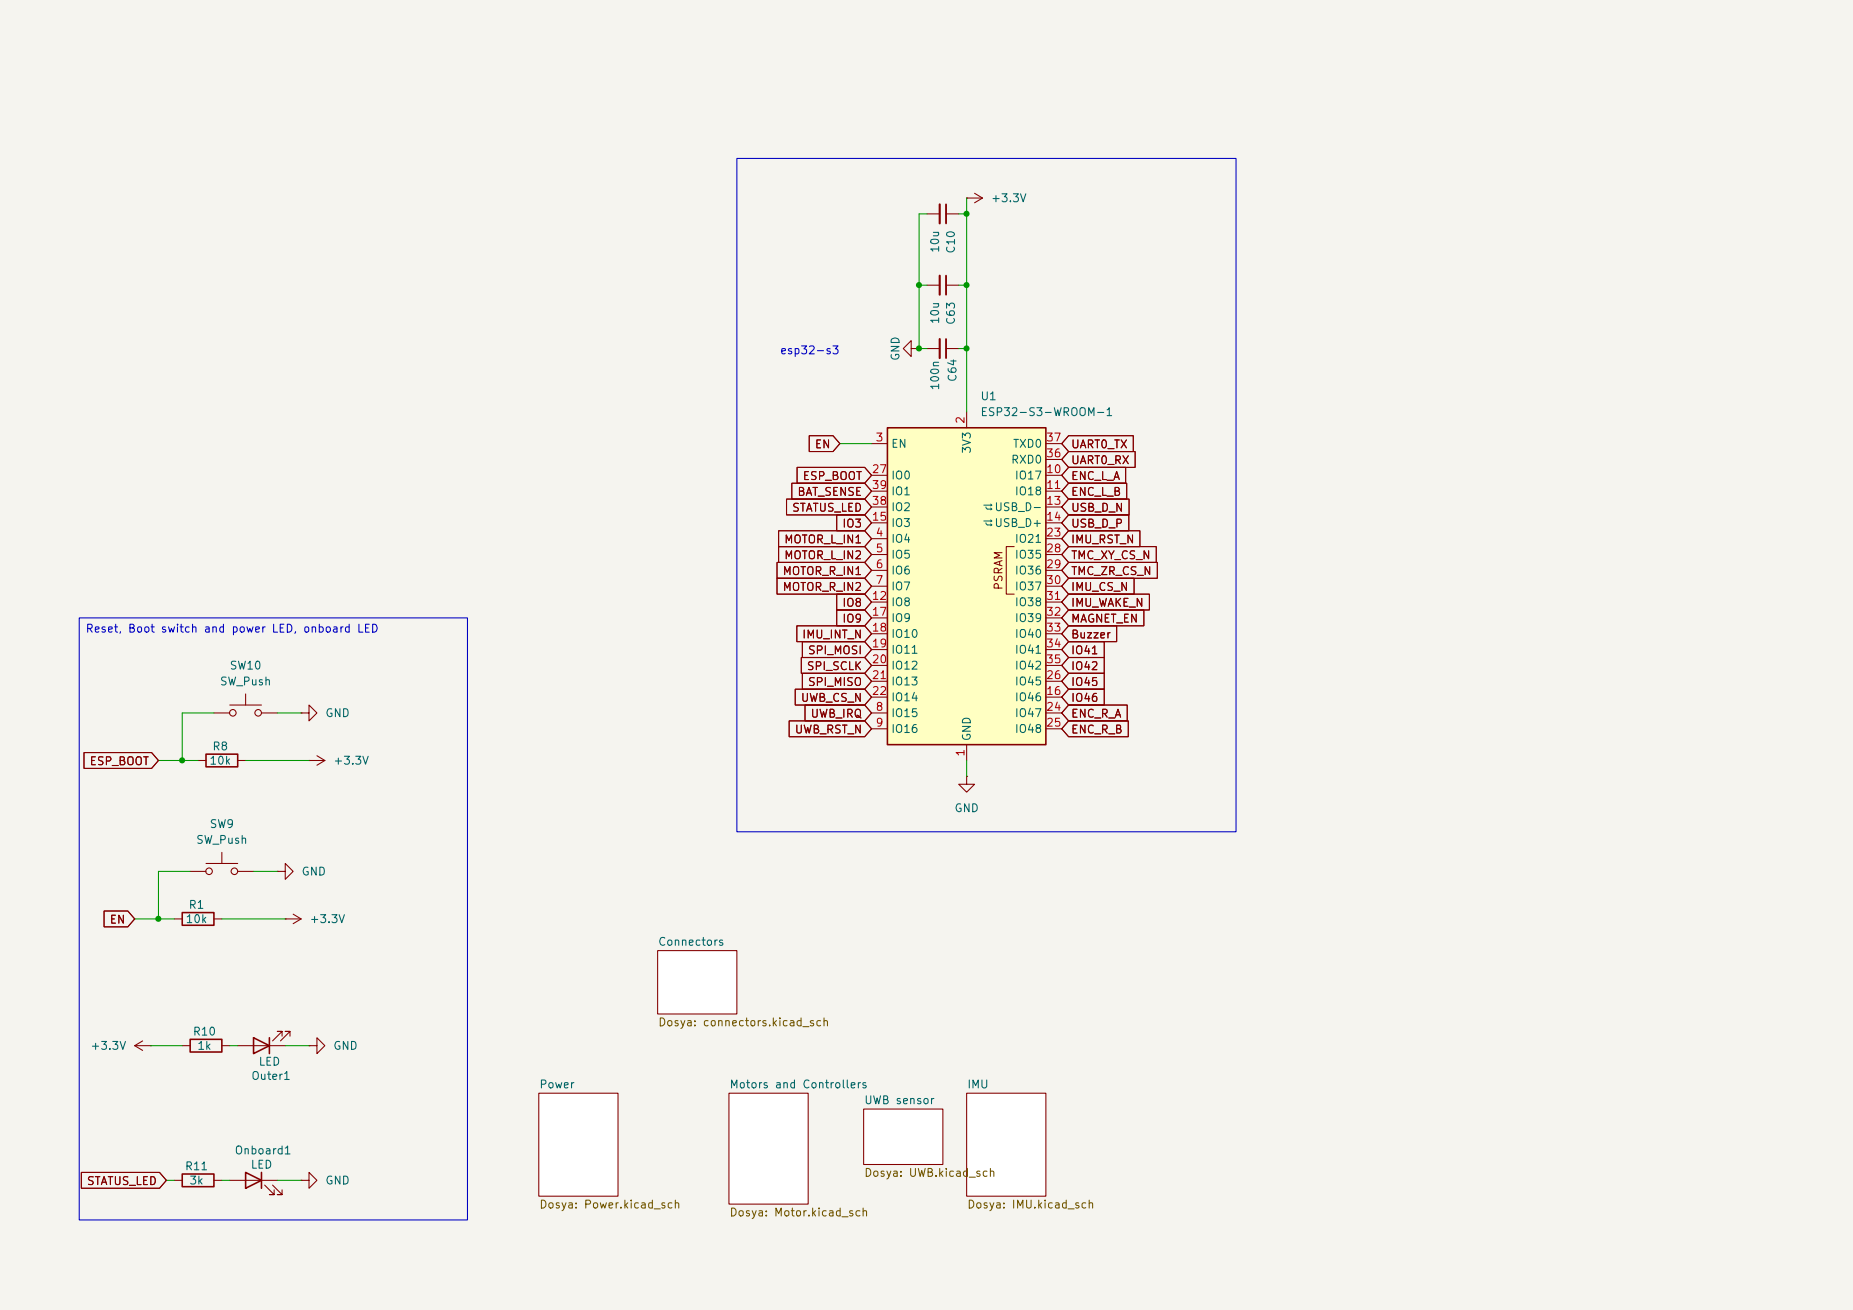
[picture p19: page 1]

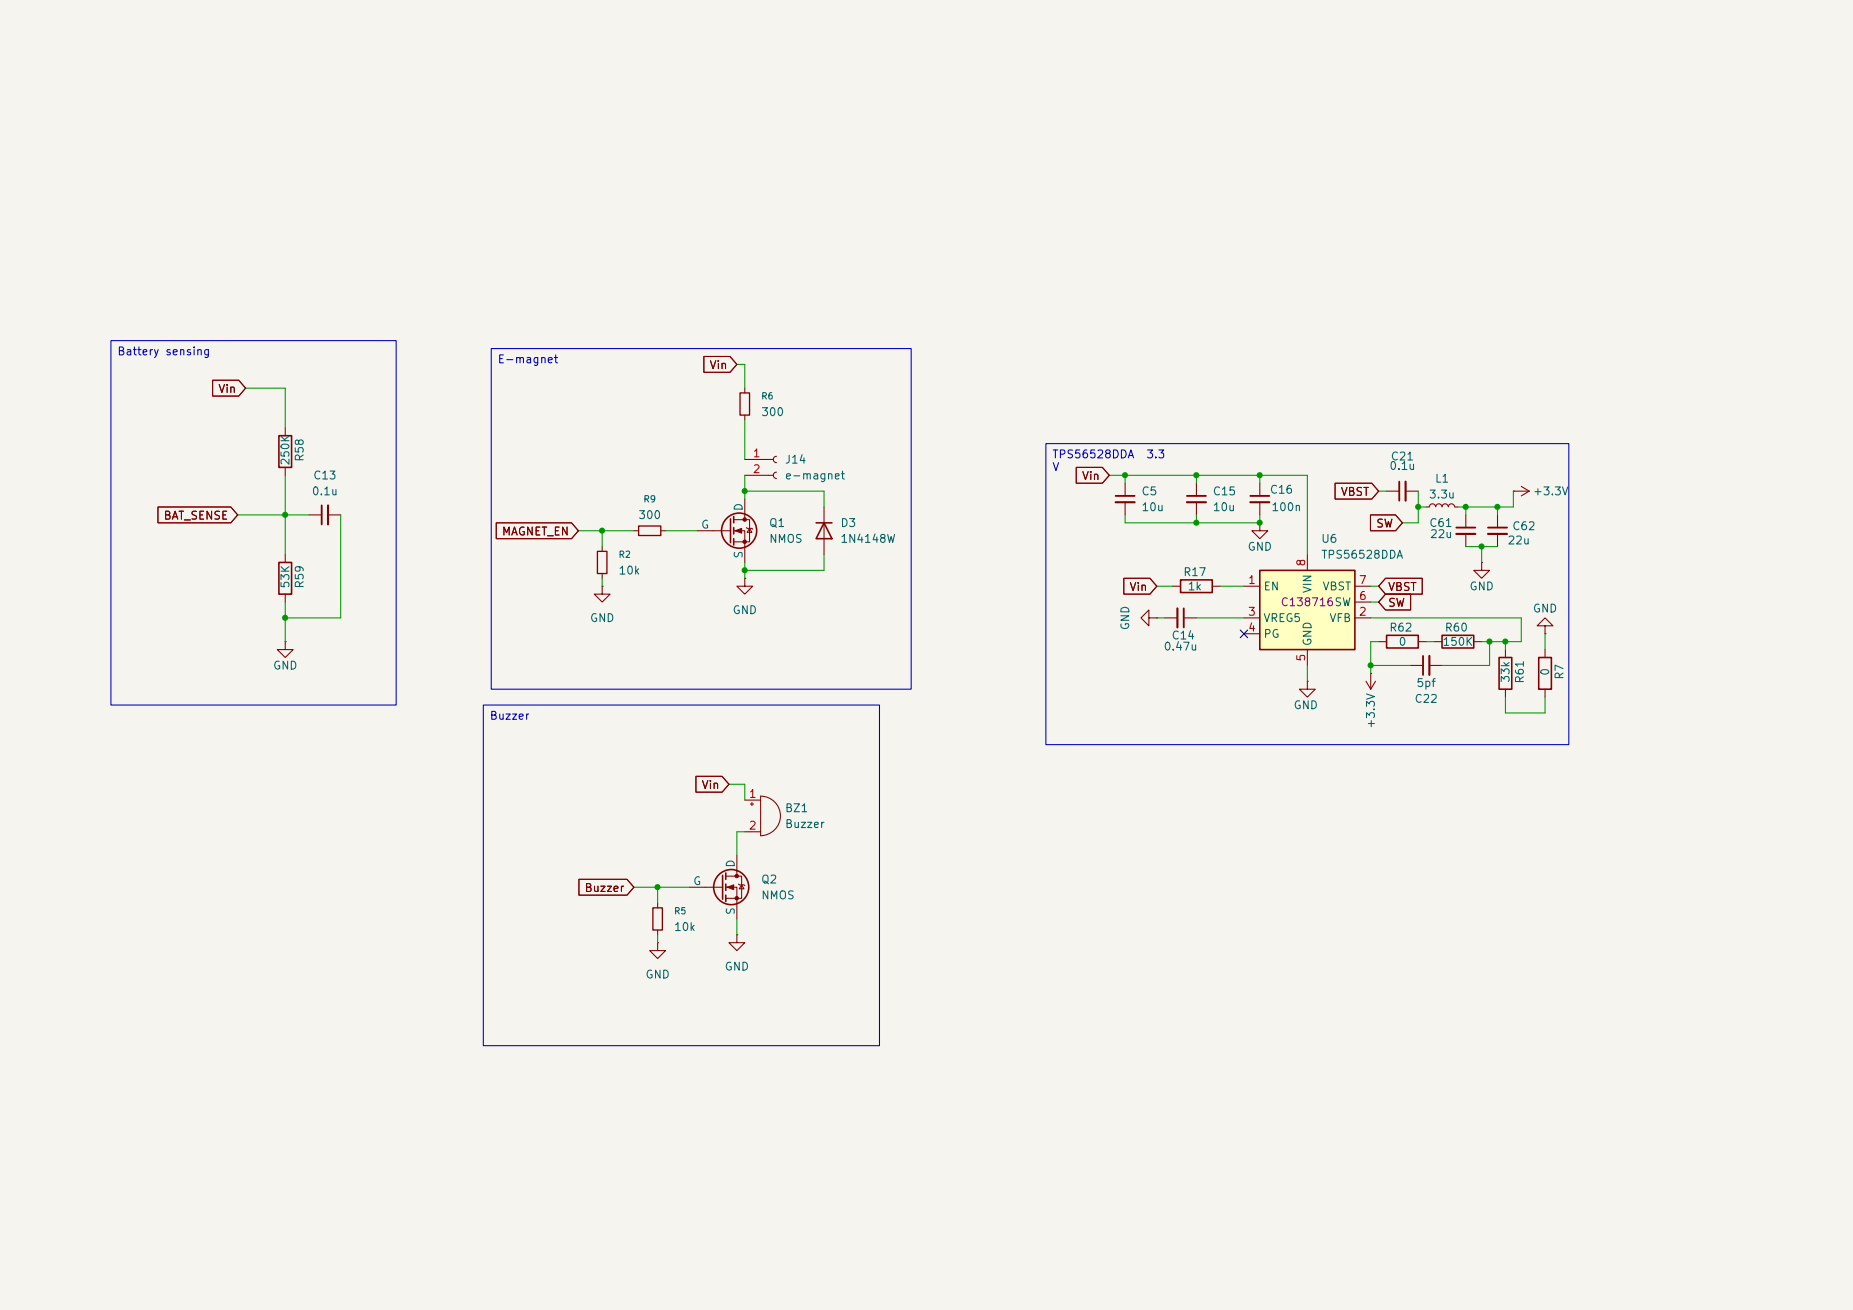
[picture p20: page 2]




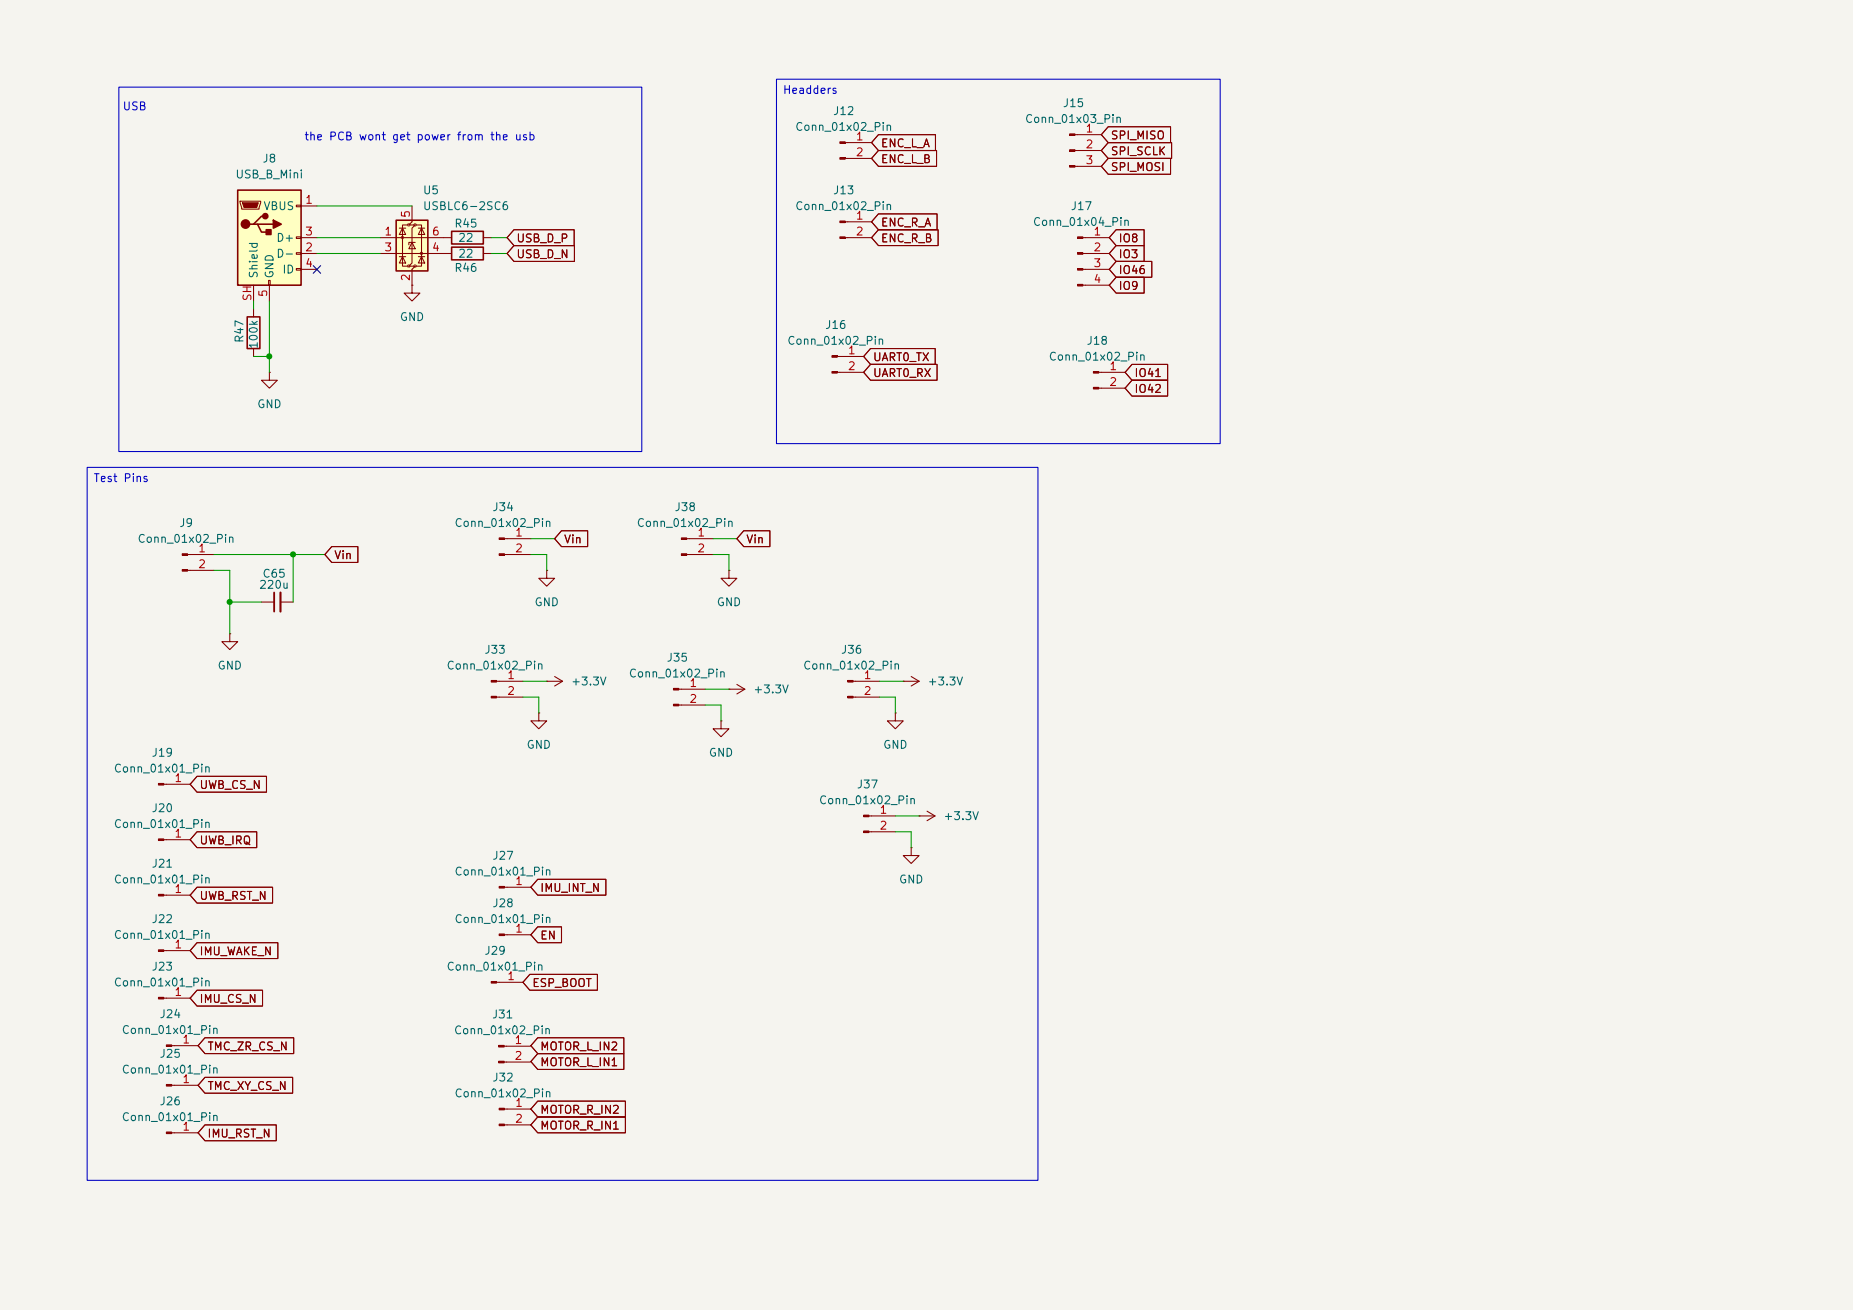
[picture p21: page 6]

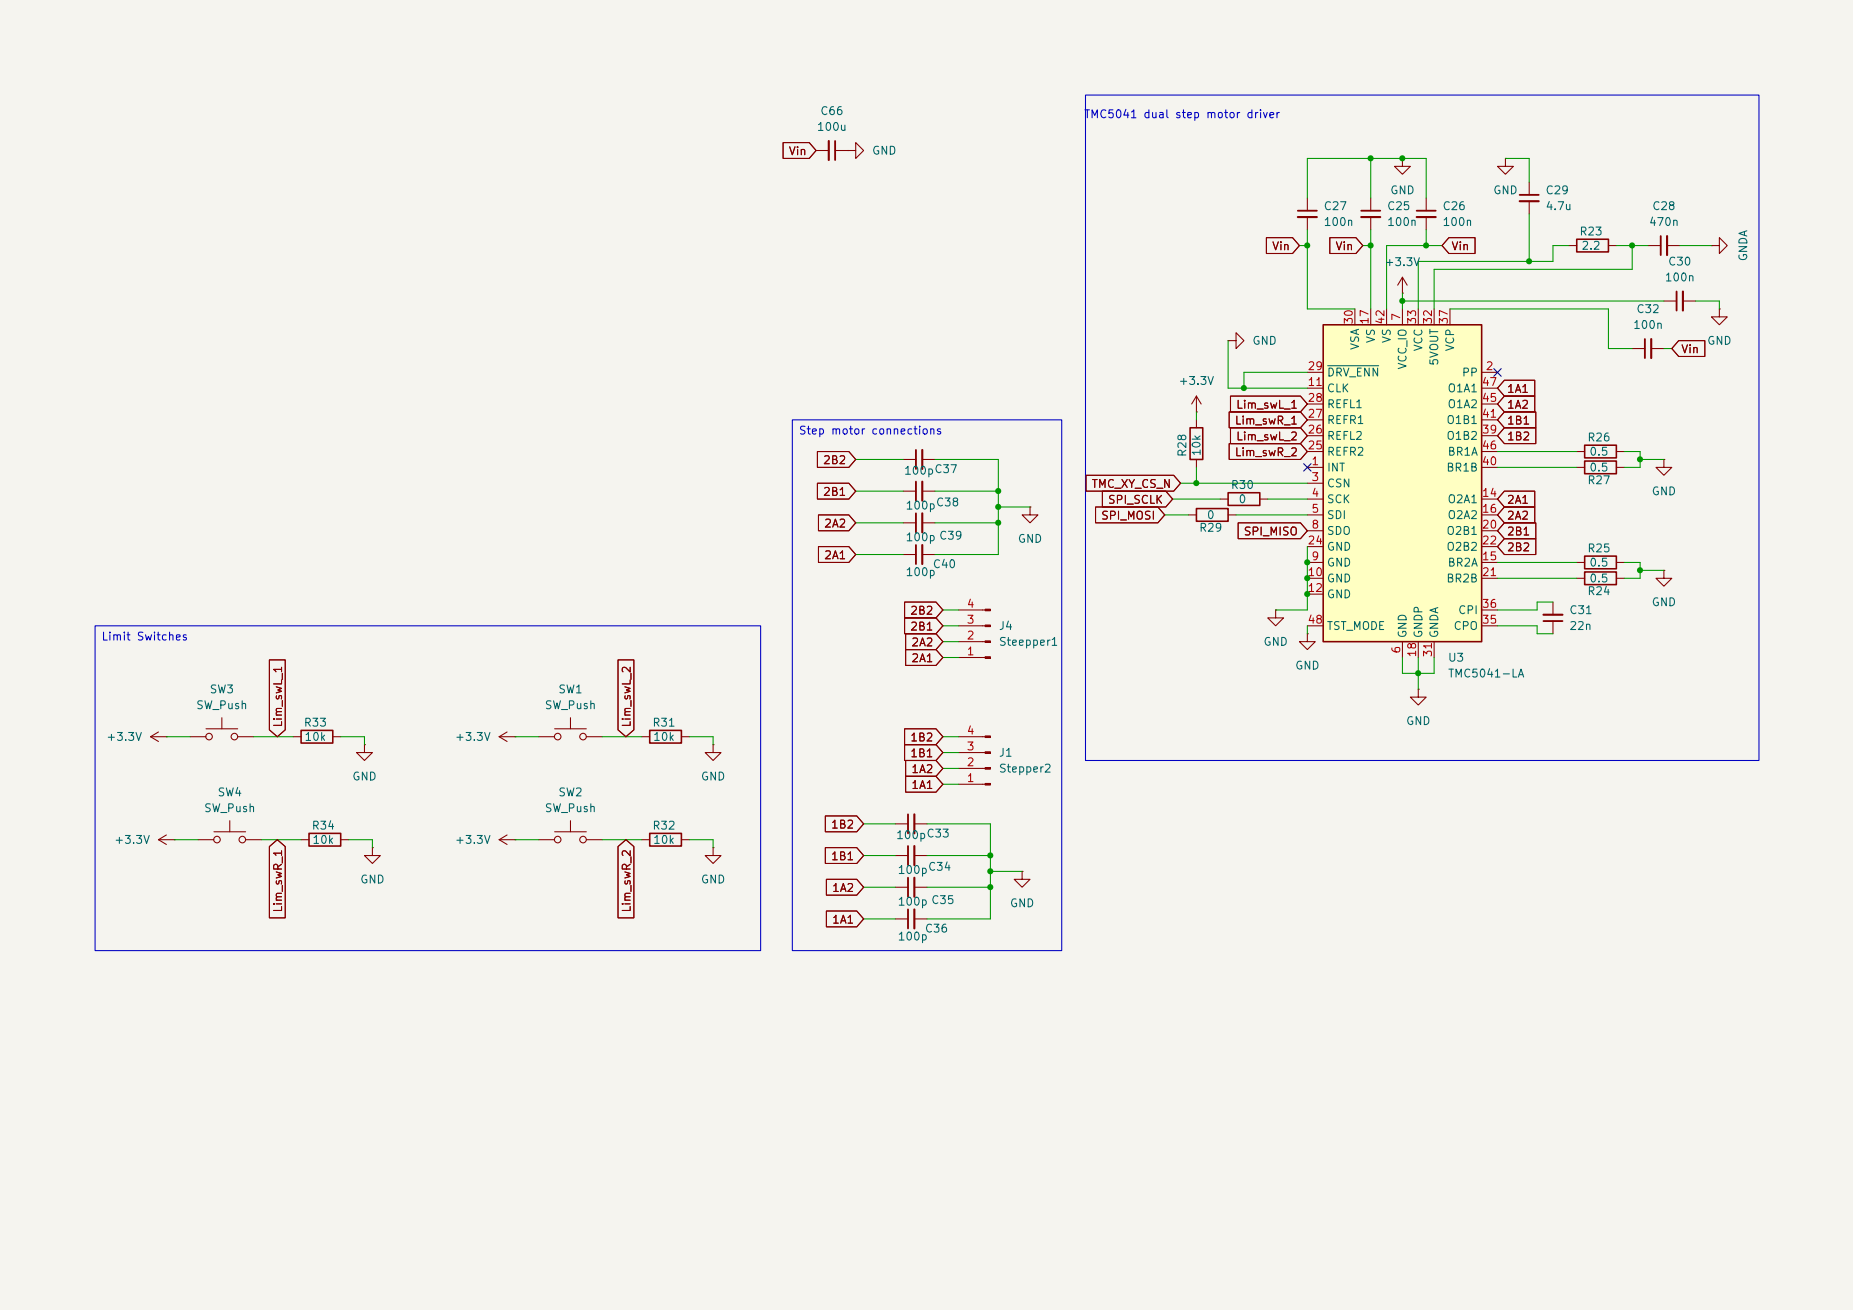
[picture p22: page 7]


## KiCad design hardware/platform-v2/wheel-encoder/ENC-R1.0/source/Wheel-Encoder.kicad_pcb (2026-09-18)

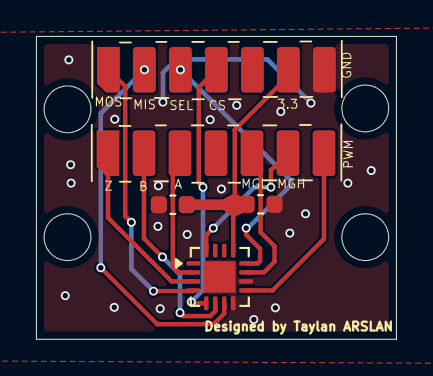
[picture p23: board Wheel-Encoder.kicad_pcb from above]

Board: 2 copper layers, 20.0 x 16.8 mm, 5 parts (0 on the bottom side), 12 nets.

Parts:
C1: 1u; C_0603_1608Metric
C2: 100n; C_0603_1608Metric
J1, J2: Conn_01x07_Socket; 7 pin smd conn 2.54
U1: MA730; QFN-16-1EP_3x3mm_P0.5mm_EP1.75x1.75mm

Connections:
+3.3V: C1.2, C2.2, J1.6, U1.13 (VDD)
A: J2.3, U1.2 (A)
B: J2.2, U1.6 (B)
CS: J1.4, U1.5 (~CS)
GND: C1.1, C2.1, J1.7, U1.8 (GND), U1.10 (TEST), U1.17 (PAD)
MGH: J2.6, U1.16 (MGH)
MGL: J2.5, U1.11 (MGL)
MISO: J1.2, U1.7 (MISO)
MOSI: J1.1, U1.4 (MOSI)
PWM: J2.7, U1.9 (PWM)
SCLK: J1.3, U1.12 (SCLK)
Z: J2.1, U1.3 (Z)

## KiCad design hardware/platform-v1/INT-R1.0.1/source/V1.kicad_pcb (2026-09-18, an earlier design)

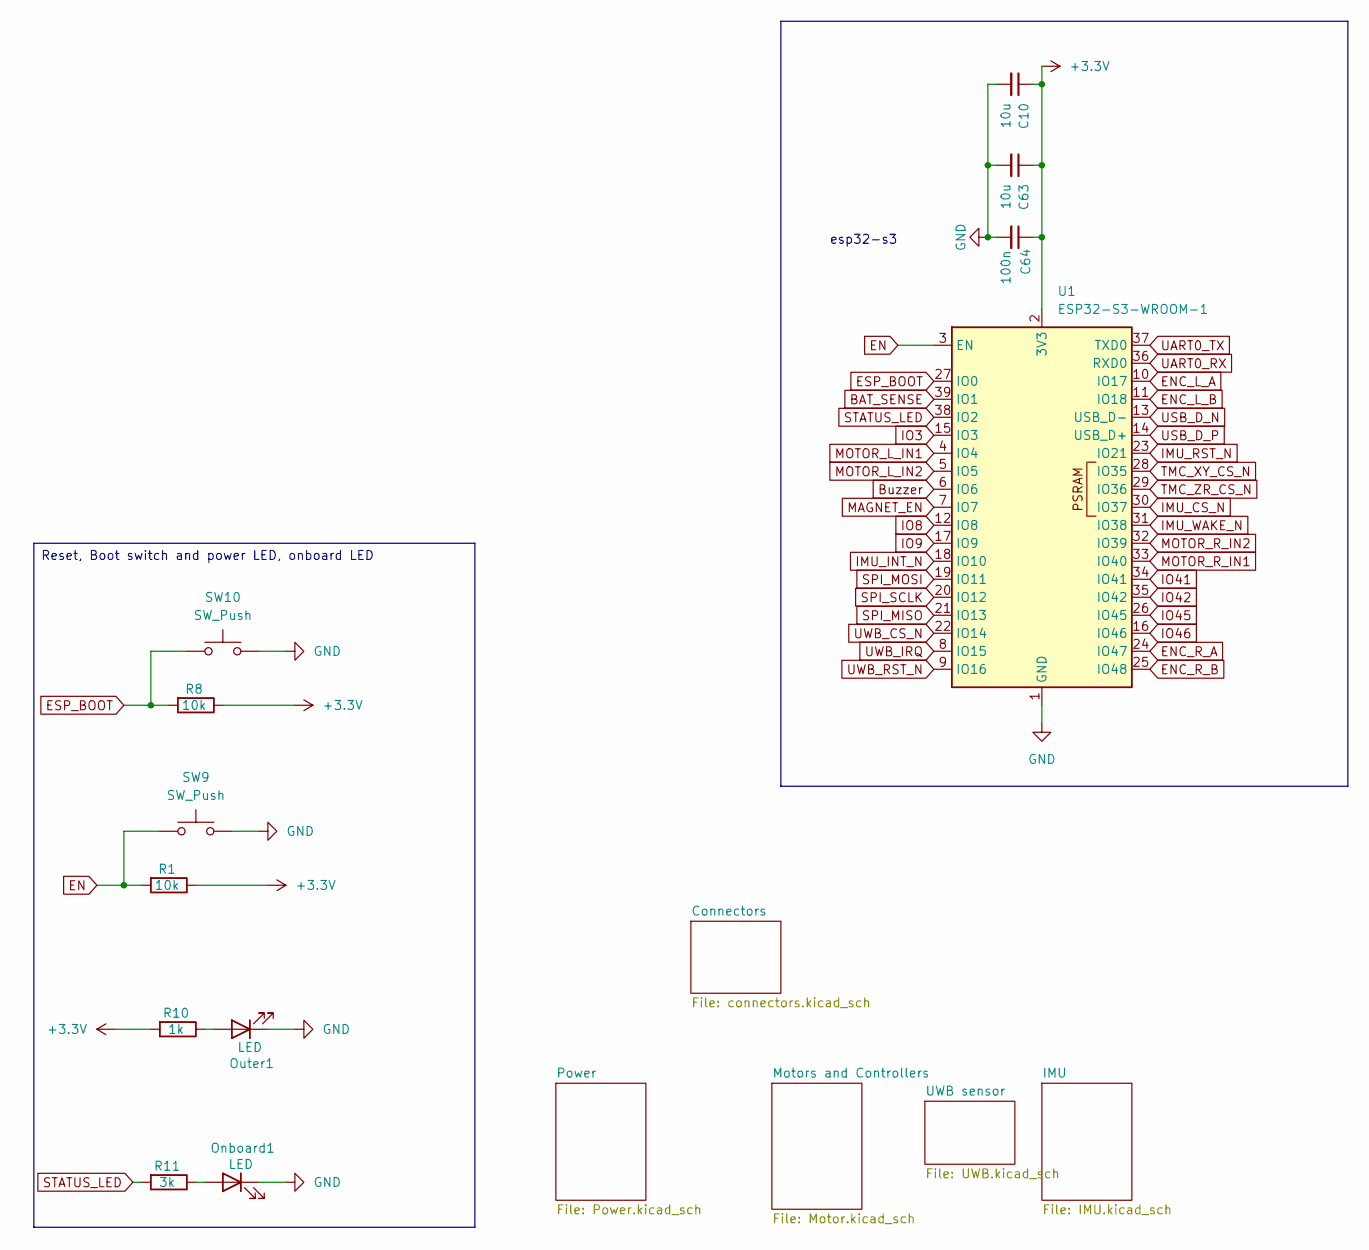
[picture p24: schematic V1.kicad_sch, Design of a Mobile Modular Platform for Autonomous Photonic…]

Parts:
C10, C63: 10u; C_0603_1608Metric_Pad1.08x0.95mm_HandSolder; LCSC Part # C15850
C64: 100n; C_0402_1005Metric_Pad0.74x0.62mm_HandSolder; LCSC Part # C15850
Onboard1: LED; LED_0603_1608Metric_Pad1.05x0.95mm_HandSolder; LCSC Part # C2297
Outer1: LED; LED_0603_1608Metric_Pad1.05x0.95mm_HandSolder
R1, R8: 10k; R_0402_1005Metric_Pad0.72x0.64mm_HandSolder; LCSC Part # C21190
R10: 1k; R_0402_1005Metric_Pad0.72x0.64mm_HandSolder; LCSC Part # C21190
R11: 3k; R_0402_1005Metric_Pad0.72x0.64mm_HandSolder; LCSC Part # C4211
SW9, SW10: SW_Push; SW_SPST_CK_KXT3
U1: ESP32-S3-WROOM-1

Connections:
BAT_SENSE: U1.39 (IO1); also elsewhere on the board
Buzzer: U1.6 (IO6); also elsewhere on the board
EN: R1.2, SW9.1, U1.3 (EN); also elsewhere on the board
ENC_L_A: U1.10 (IO17); also elsewhere on the board
ENC_L_B: U1.11 (IO18); also elsewhere on the board
ENC_R_A: U1.24 (IO47); also elsewhere on the board
ENC_R_B: U1.25 (IO48); also elsewhere on the board
ESP_BOOT: R8.2, SW10.1, U1.27 (IO0); also elsewhere on the board
GND: C10.2, C63.2, C64.2, Onboard1.1 (K), Outer1.1 (K), SW9.2, SW10.2, U1.1 (GND), U1.40 (GND), U1.41 (GND); also elsewhere on the board
IMU_CS_N: U1.30 (IO37); also elsewhere on the board
IMU_INT_N: U1.18 (IO10); also elsewhere on the board
IMU_RST_N: U1.23 (IO21); also elsewhere on the board
IMU_WAKE_N: U1.31 (IO38); also elsewhere on the board
IO3: U1.15 (IO3); also elsewhere on the board
IO8: U1.12 (IO8); also elsewhere on the board
IO9: U1.17 (IO9); also elsewhere on the board
IO41: U1.34 (IO41); also elsewhere on the board
IO42: U1.35 (IO42); also elsewhere on the board
IO45: U1.26 (IO45); also elsewhere on the board
IO46: U1.16 (IO46); also elsewhere on the board
MAGNET_EN: U1.7 (IO7); also elsewhere on the board
MOTOR_L_IN1: U1.4 (IO4); also elsewhere on the board
MOTOR_L_IN2: U1.5 (IO5); also elsewhere on the board
MOTOR_R_IN1: U1.33 (IO40); also elsewhere on the board
MOTOR_R_IN2: U1.32 (IO39); also elsewhere on the board
unnamed: Onboard1.2 (A), R11.1
unnamed: Outer1.2 (A), R10.1
PS1: C10.1, C63.1, C64.1, R1.1, R8.1, R10.2, U1.2 (3V3); also elsewhere on the board
SPI_MISO: U1.21 (IO13); also elsewhere on the board
SPI_MOSI: U1.19 (IO11); also elsewhere on the board
SPI_SCLK: U1.20 (IO12); also elsewhere on the board
STATUS_LED: R11.2, U1.38 (IO2)
TMC_XY_CS_N: U1.28 (IO35); also elsewhere on the board
TMC_ZR_CS_N: U1.29 (IO36); also elsewhere on the board
UART0_RX: U1.36 (RXD0); also elsewhere on the board
UART0_TX: U1.37 (TXD0); also elsewhere on the board
USB_D_N: U1.13 (USB_D-); also elsewhere on the board
USB_D_P: U1.14 (USB_D+); also elsewhere on the board
UWB_CS_N: U1.22 (IO14); also elsewhere on the board
UWB_IRQ: U1.8 (IO15); also elsewhere on the board
UWB_RST_N: U1.9 (IO16); also elsewhere on the board

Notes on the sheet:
esp32-s3
Reset, Boot switch and power LED, onboard LED

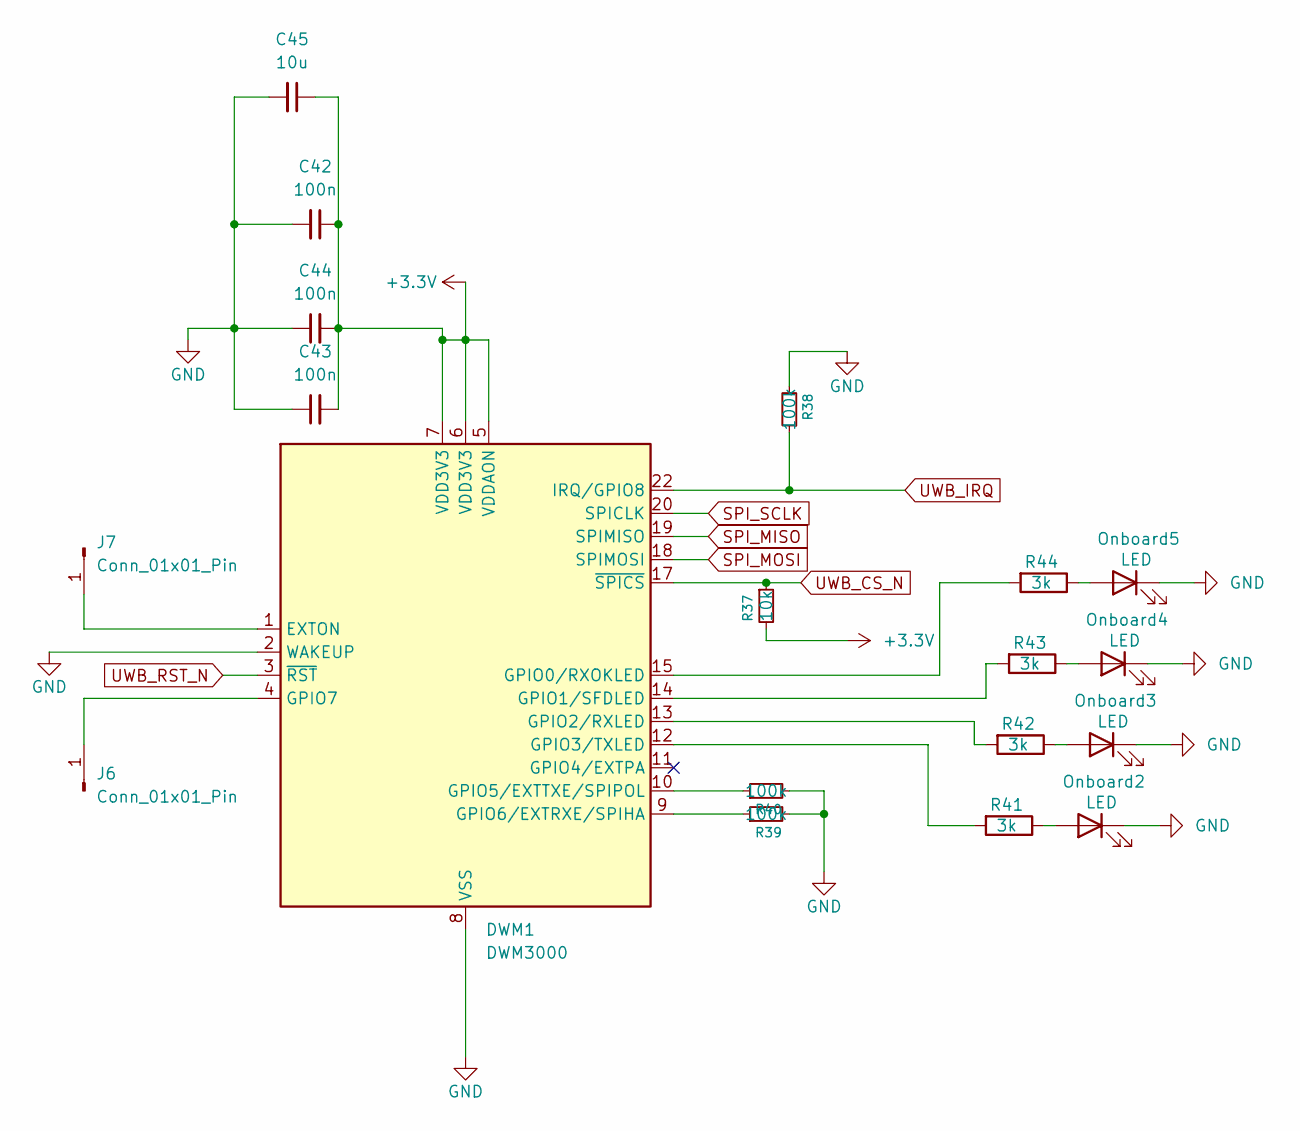
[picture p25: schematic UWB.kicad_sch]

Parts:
C42, C43, C44: 100n; C_0402_1005Metric_Pad0.74x0.62mm_HandSolder; LCSC Part # C14663
C45: 10u; C_0603_1608Metric_Pad1.08x0.95mm_HandSolder; LCSC Part # C14663
DWM1: DWM3000; DWM1000
J6, J7: Conn_01x01_Pin; SolderWirePad_1x01_SMD_1x2mm
Onboard2, Onboard3, Onboard4, Onboard5: LED; LED_0603_1608Metric_Pad1.05x0.95mm_HandSolder; LCSC Part # C2297
R37: 10k; R_0402_1005Metric_Pad0.72x0.64mm_HandSolder
R38, R39, R40: 100k; R_0402_1005Metric_Pad0.72x0.64mm_HandSolder
R41, R42, R43, R44: 3k; R_0402_1005Metric_Pad0.72x0.64mm_HandSolder; LCSC Part # C4211

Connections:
GND: C42.2, C43.1, C44.1, C45.2, DWM1.2 (WAKEUP), DWM1.8 (VSS), DWM1.16 (VSS), DWM1.21 (VSS), DWM1.23 (VSS), DWM1.24 (VSS), Onboard2.1 (K), Onboard3.1 (K), Onboard4.1 (K), Onboard5.1 (K), R38.2, R39.2, R40.2; also elsewhere on the board
unnamed: DWM1.1 (EXTON), J7.1 (Pin_1_1)
unnamed: DWM1.15 (GPIO0/RXOKLED), R44.2
unnamed: DWM1.14 (GPIO1/SFDLED), R43.2
unnamed: DWM1.13 (GPIO2/RXLED), R42.2
unnamed: DWM1.12 (GPIO3/TXLED), R41.2
unnamed: DWM1.10 (GPIO5/EXTTXE/SPIPOL), R40.1
unnamed: DWM1.9 (GPIO6/EXTRXE/SPIHA), R39.1
unnamed: DWM1.4 (GPIO7), J6.1 (Pin_1_1)
unnamed: Onboard2.2 (A), R41.1
unnamed: Onboard3.2 (A), R42.1
unnamed: Onboard4.2 (A), R43.1
unnamed: Onboard5.2 (A), R44.1
PS1: C42.1, C43.2, C44.2, C45.1, DWM1.5 (VDDAON), DWM1.6 (VDD3V3), DWM1.7 (VDD3V3), R37.2; also elsewhere on the board
SPI_MISO: DWM1.19 (SPIMISO); also elsewhere on the board
SPI_MOSI: DWM1.18 (SPIMOSI); also elsewhere on the board
SPI_SCLK: DWM1.20 (SPICLK); also elsewhere on the board
UWB_CS_N: DWM1.17 (~SPICS), R37.1; also elsewhere on the board
UWB_IRQ: DWM1.22 (IRQ/GPIO8), R38.1; also elsewhere on the board
UWB_RST_N: DWM1.3 (~RST); also elsewhere on the board

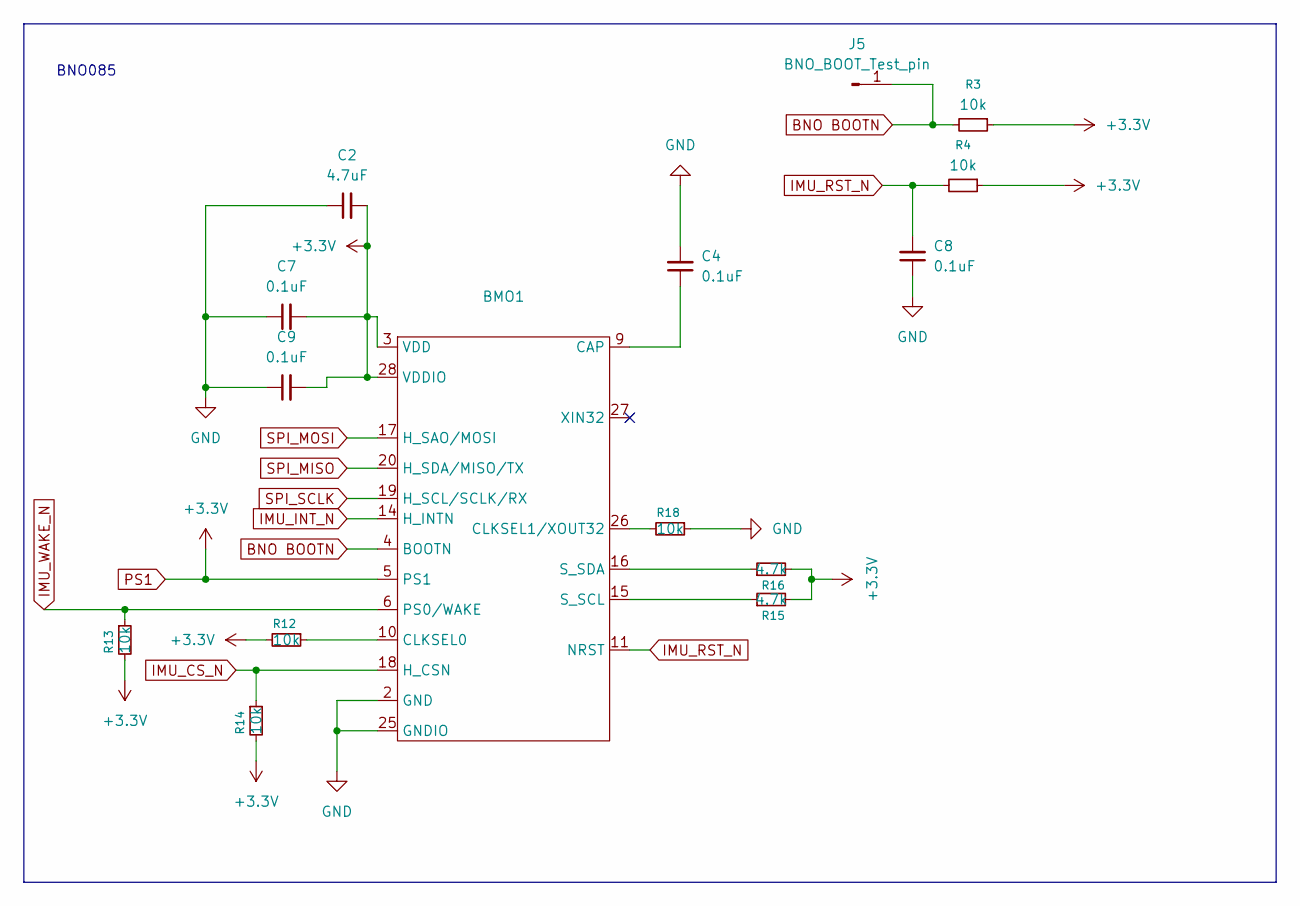
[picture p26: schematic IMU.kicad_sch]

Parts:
BMO1: LGA-28_5.2x3.8mm_P0.5mm
C2: 4.7uF; C_0402_1005Metric_Pad0.74x0.62mm_HandSolder
C4, C7, C8, C9: 0.1uF; C_0402_1005Metric_Pad0.74x0.62mm_HandSolder
J5: BNO_BOOT_Test_pin; SolderWirePad_1x01_SMD_1x2mm
R3, R4, R12, R13, R14, R18: 10k; R_0402_1005Metric_Pad0.72x0.64mm_HandSolder
R15, R16: 4.7k; R_0402_1005Metric_Pad0.72x0.64mm_HandSolder

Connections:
BNO BOOTN: BMO1.4 (BOOTN), J5.1 (Pin_1_1), R3.2
GND: BMO1.2 (GND), BMO1.25 (GNDIO), C2.1, C4.2, C7.1, C8.1, C9.1, R18.1; also elsewhere on the board
IMU_CS_N: BMO1.18 (H_CSN), R14.1; also elsewhere on the board
IMU_INT_N: BMO1.14 (H_INTN); also elsewhere on the board
IMU_RST_N: BMO1.11 (NRST), C8.2, R4.2; also elsewhere on the board
IMU_WAKE_N: BMO1.6 (PS0/WAKE), R13.1; also elsewhere on the board
unnamed: BMO1.9 (CAP), C4.1
unnamed: BMO1.10 (CLKSEL0), R12.1
unnamed: BMO1.26 (CLKSEL1/XOUT32), R18.2
unnamed: BMO1.15 (S_SCL), R15.1
unnamed: BMO1.16 (S_SDA), R16.1
PS1: BMO1.3 (VDD), BMO1.5 (PS1), BMO1.8 (nc), BMO1.28 (VDDIO), C2.2, C7.2, C9.2, R3.1, R4.1, R12.2, R13.2, R14.2, R15.2, R16.2; also elsewhere on the board
SPI_MISO: BMO1.20 (H_SDA/MISO/TX); also elsewhere on the board
SPI_MOSI: BMO1.17 (H_SAO/MOSI); also elsewhere on the board
SPI_SCLK: BMO1.19 (H_SCL/SCLK/RX); also elsewhere on the board

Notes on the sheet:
BNO085

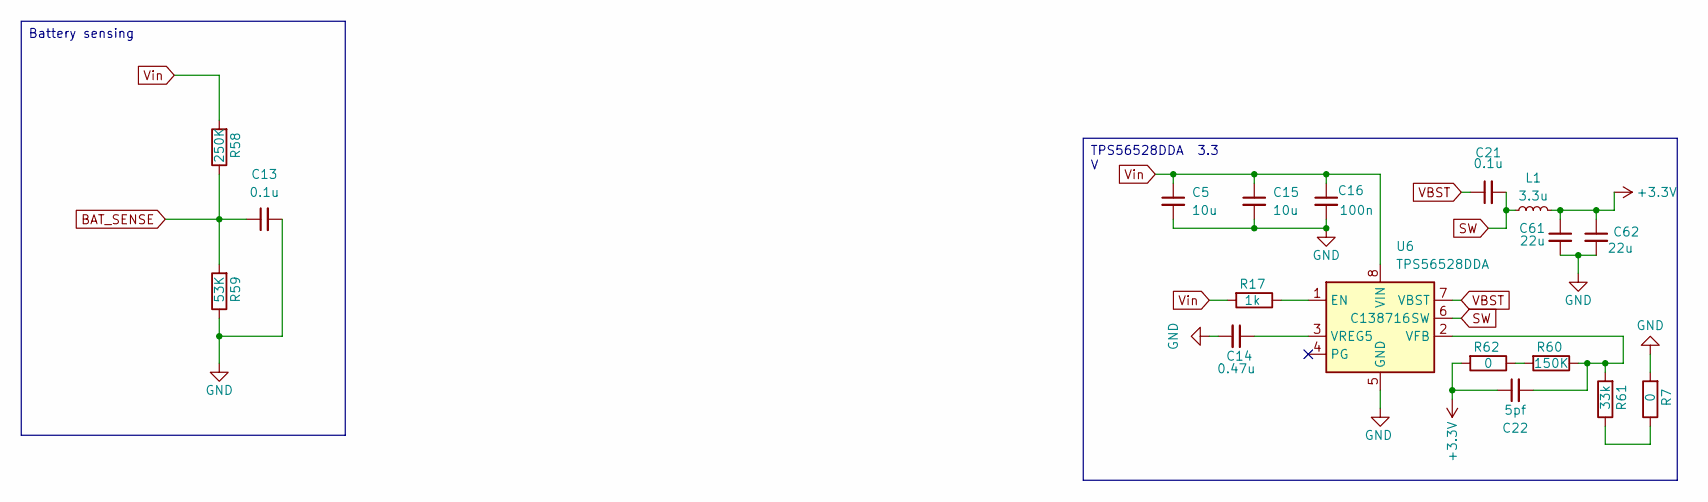
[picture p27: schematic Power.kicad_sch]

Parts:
C5, C15: 10u; C_0603_1608Metric_Pad1.08x0.95mm_HandSolder; LCSC Part # C15850
C13: 0.1u; C_0402_1005Metric_Pad0.74x0.62mm_HandSolder; LCSC Part # C15850
C14: 0.47u; C_0402_1005Metric_Pad0.74x0.62mm_HandSolder; LCSC Part # C1623
C16: 100n; C_0402_1005Metric_Pad0.74x0.62mm_HandSolder; LCSC Part # C15850
C21: 0.1u; C_0402_1005Metric_Pad0.74x0.62mm_HandSolder; LCSC Part # C14663
C22: 5pf; C_0402_1005Metric_Pad0.74x0.62mm_HandSolder; LCSC Part # C1653
C61, C62: 22u; C_0603_1608Metric_Pad1.08x0.95mm_HandSolder; LCSC Part # C45783
L1: 3.3u; L_Abracon_ASPI-0630LR
R7: 0; R_0603_1608Metric_Pad0.98x0.95mm_HandSolder; LCSC Part # C4216
R17: 1k; R_0402_1005Metric_Pad0.72x0.64mm_HandSolder; LCSC Part # C21190
R58: 250K; R_0402_1005Metric_Pad0.72x0.64mm_HandSolder; LCSC Part # C23182
R59: 53K; R_0402_1005Metric_Pad0.72x0.64mm_HandSolder; LCSC Part # C23182
R60: 150K; R_0603_1608Metric_Pad0.98x0.95mm_HandSolder; LCSC Part # C22807
R61: 33k; R_0603_1608Metric_Pad0.98x0.95mm_HandSolder; LCSC Part # C4216
R62: 0; R_0603_1608Metric_Pad0.98x0.95mm_HandSolder; LCSC Part # C22807
U6: TPS56528DDA; Texas_HSOP-8-1EP_3.9x4.9mm_P1.27mm_ThermalVias; LCSC Part # C138716

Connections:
BAT_SENSE: C13.1, R58.1, R59.2; also elsewhere on the board
GND: C5.2, C13.2, C14.2, C15.2, C16.2, C61.2, C62.2, R7.2, R59.1, U6.5 (GND), U6.9 (GND); also elsewhere on the board
unnamed: R60.2, R62.1
unnamed: R7.1, R61.1
unnamed: R17.1, U6.1 (EN)
unnamed: C22.2, R60.1, R61.2, U6.2 (VFB)
unnamed: C14.1, U6.3 (VREG5)
PS1: C22.1, C61.1, C62.1, L1.2, R62.2; also elsewhere on the board
SW: C21.2, L1.1, U6.6 (SW)
VBST: C21.1, U6.7 (VBST)
Vin: C5.1, C15.1, C16.1, R17.2, R58.2, U6.8 (VIN); also elsewhere on the board

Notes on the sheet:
TPS56528DDA 3.3 V
Battery sensing

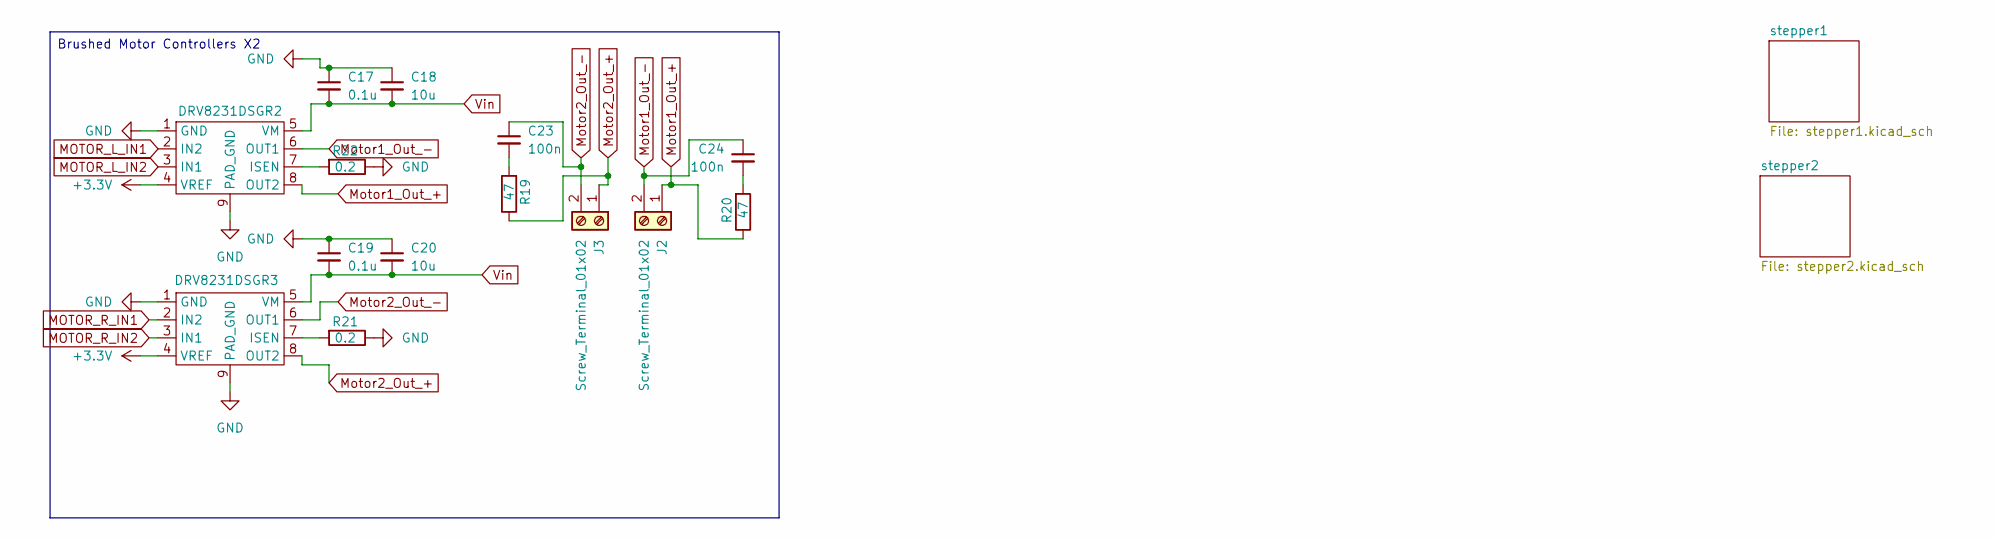
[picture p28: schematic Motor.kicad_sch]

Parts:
C17, C19: 0.1u; C_0402_1005Metric_Pad0.74x0.62mm_HandSolder; LCSC Part # C14663
C18, C20: 10u; C_0603_1608Metric_Pad1.08x0.95mm_HandSolder; LCSC Part # C5464883
C23, C24: 100n; C_0402_1005Metric_Pad0.74x0.62mm_HandSolder; LCSC Part # C14663
DRV8231DSGR2, DRV8231DSGR3: HSOP-8-1EP_3.9x4.9mm_P1.27mm_EP2.41x3.1mm_ThermalVias; LCSC Part # C3681197
J2: Screw_Terminal_01x02; PinHeader_2x01_P2.54mm_Vertical
J3: Screw_Terminal_01x02; PinSocket_2x01_P2.54mm_Vertical
R19, R20: 47; R_1206_3216Metric_Pad1.30x1.75mm_HandSolder; LCSC Part # C23182
R21, R22: 0.2; R_2512_6332Metric_Pad1.40x3.35mm_HandSolder; LCSC Part # C23182

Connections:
GND: C17.1, C18.1, C19.1, C20.1, DRV8231DSGR2.1 (GND), DRV8231DSGR2.9 (PAD_GND), DRV8231DSGR3.1 (GND), DRV8231DSGR3.9 (PAD_GND), R21.1, R22.1; also elsewhere on the board
MOTOR_L_IN1: DRV8231DSGR2.2 (IN2); also elsewhere on the board
MOTOR_L_IN2: DRV8231DSGR2.3 (IN1); also elsewhere on the board
MOTOR_R_IN1: DRV8231DSGR3.2 (IN2); also elsewhere on the board
MOTOR_R_IN2: DRV8231DSGR3.3 (IN1); also elsewhere on the board
Motor1_Out_+: DRV8231DSGR2.8 (OUT2), J2.1, R20.1
Motor1_Out_-: C24.1, DRV8231DSGR2.6 (OUT1), J2.2
Motor2_Out_+: DRV8231DSGR3.8 (OUT2), J3.1, R19.1
Motor2_Out_-: C23.1, DRV8231DSGR3.6 (OUT1), J3.2
unnamed: C23.2, R19.2
unnamed: C24.2, R20.2
unnamed: DRV8231DSGR2.7 (ISEN), R22.2
unnamed: DRV8231DSGR3.7 (ISEN), R21.2
PS1: DRV8231DSGR2.4 (VREF), DRV8231DSGR3.4 (VREF); also elsewhere on the board
Vin: C17.2, C18.2, C19.2, C20.2, DRV8231DSGR2.5 (VM), DRV8231DSGR3.5 (VM); also elsewhere on the board

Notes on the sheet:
Brushed Motor Controllers X2

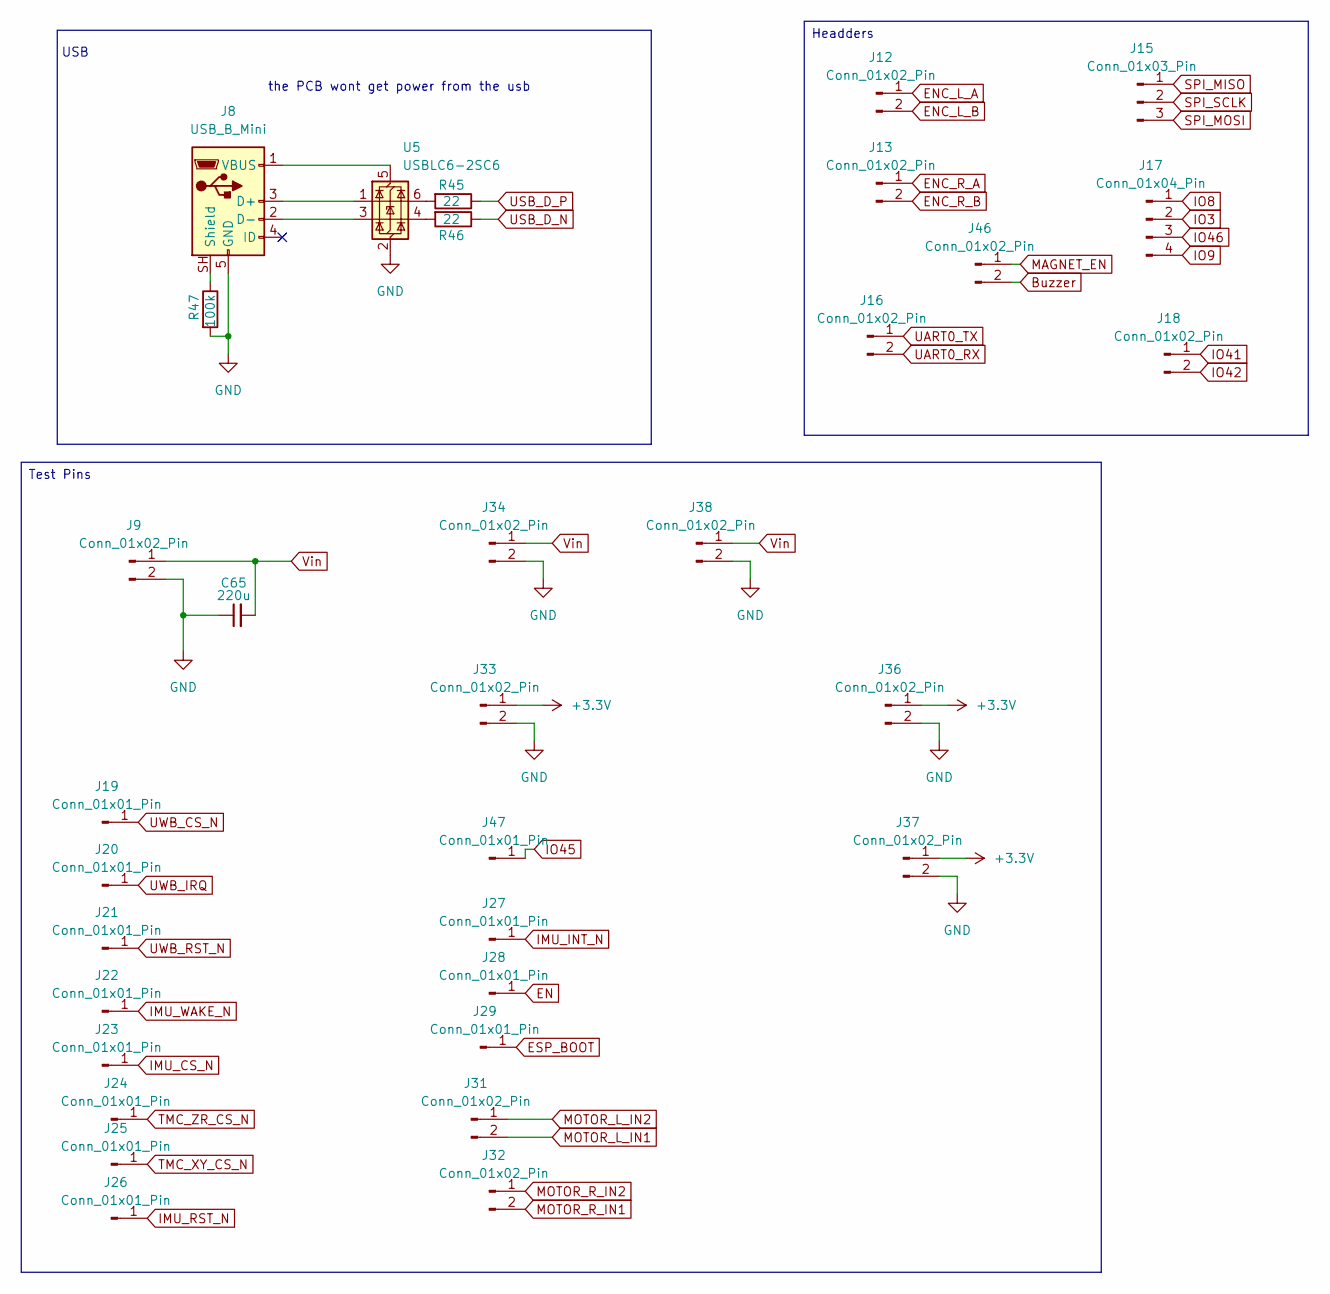
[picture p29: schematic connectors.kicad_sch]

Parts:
C65: 220u; C_Radial_D10.0mm_H12.5mm_P5.00mm; LCSC Part # C14663
J8: USB_B_Mini; USB_Mini-B_Wuerth_65100516121_Horizontal
J9, J12, J13, J16, J18, J31, J32, J33, J34, J36, J37, J46: Conn_01x02_Pin; PinHeader_1x02_P1.00mm_Vertical
J15: Conn_01x03_Pin; PinHeader_1x03_P1.00mm_Vertical
J17: Conn_01x04_Pin; PinHeader_1x04_P1.00mm_Vertical
J19, J20, J21, J22, J23, J24, J25, J26, J27, J28, J29, J47: Conn_01x01_Pin; SolderWirePad_1x01_SMD_1x2mm
J38: Conn_01x02_Pin; PinHeader_1x02_P2.54mm_Vertical
R45, R46: 22; R_0402_1005Metric_Pad0.72x0.64mm_HandSolder; LCSC Part # C4211
R47: 100k; R_0402_1005Metric_Pad0.72x0.64mm_HandSolder; LCSC Part # C4211
U5: USBLC6-2SC6; SOT-23-6

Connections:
Buzzer: J46.2; also elsewhere on the board
EN: J28.1 (Pin_1_1); also elsewhere on the board
ENC_L_A: J12.1; also elsewhere on the board
ENC_L_B: J12.2; also elsewhere on the board
ENC_R_A: J13.1; also elsewhere on the board
ENC_R_B: J13.2; also elsewhere on the board
ESP_BOOT: J29.1 (Pin_1_1); also elsewhere on the board
GND: C65.1, J8.5 (GND), J9.2, J33.2, J34.2, J36.2, J37.2, J38.2, R47.2, U5.2 (GND); also elsewhere on the board
IMU_CS_N: J23.1 (Pin_1_1); also elsewhere on the board
IMU_INT_N: J27.1 (Pin_1_1); also elsewhere on the board
IMU_RST_N: J26.1 (Pin_1_1); also elsewhere on the board
IMU_WAKE_N: J22.1 (Pin_1_1); also elsewhere on the board
IO3: J17.2; also elsewhere on the board
IO8: J17.1; also elsewhere on the board
IO9: J17.4; also elsewhere on the board
IO41: J18.1; also elsewhere on the board
IO42: J18.2; also elsewhere on the board
IO45: J47.1 (Pin_1_1); also elsewhere on the board
IO46: J17.3; also elsewhere on the board
MAGNET_EN: J46.1; also elsewhere on the board
MOTOR_L_IN1: J31.2; also elsewhere on the board
MOTOR_L_IN2: J31.1; also elsewhere on the board
MOTOR_R_IN1: J32.2; also elsewhere on the board
MOTOR_R_IN2: J32.1; also elsewhere on the board
unnamed: J8.3 (D+), U5.1 (I/O1)
unnamed: J8.2 (D-), U5.3 (I/O2)
unnamed: J8.SH (Shield), R47.1
unnamed: J8.1 (VBUS), U5.5 (VBUS)
unnamed: R45.2, U5.6 (I/O1)
unnamed: R46.2, U5.4 (I/O2)
PS1: J33.1, J36.1, J37.1; also elsewhere on the board
SPI_MISO: J15.1; also elsewhere on the board
SPI_MOSI: J15.3; also elsewhere on the board
SPI_SCLK: J15.2; also elsewhere on the board
TMC_XY_CS_N: J25.1 (Pin_1_1); also elsewhere on the board
TMC_ZR_CS_N: J24.1 (Pin_1_1); also elsewhere on the board
UART0_RX: J16.2; also elsewhere on the board
UART0_TX: J16.1; also elsewhere on the board
USB_D_N: R46.1; also elsewhere on the board
USB_D_P: R45.1; also elsewhere on the board
UWB_CS_N: J19.1 (Pin_1_1); also elsewhere on the board
UWB_IRQ: J20.1 (Pin_1_1); also elsewhere on the board
UWB_RST_N: J21.1 (Pin_1_1); also elsewhere on the board
Vin: C65.2, J9.1, J34.1, J38.1; also elsewhere on the board

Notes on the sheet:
USB
the PCB wont get power from the usb
Test Pins
Headders

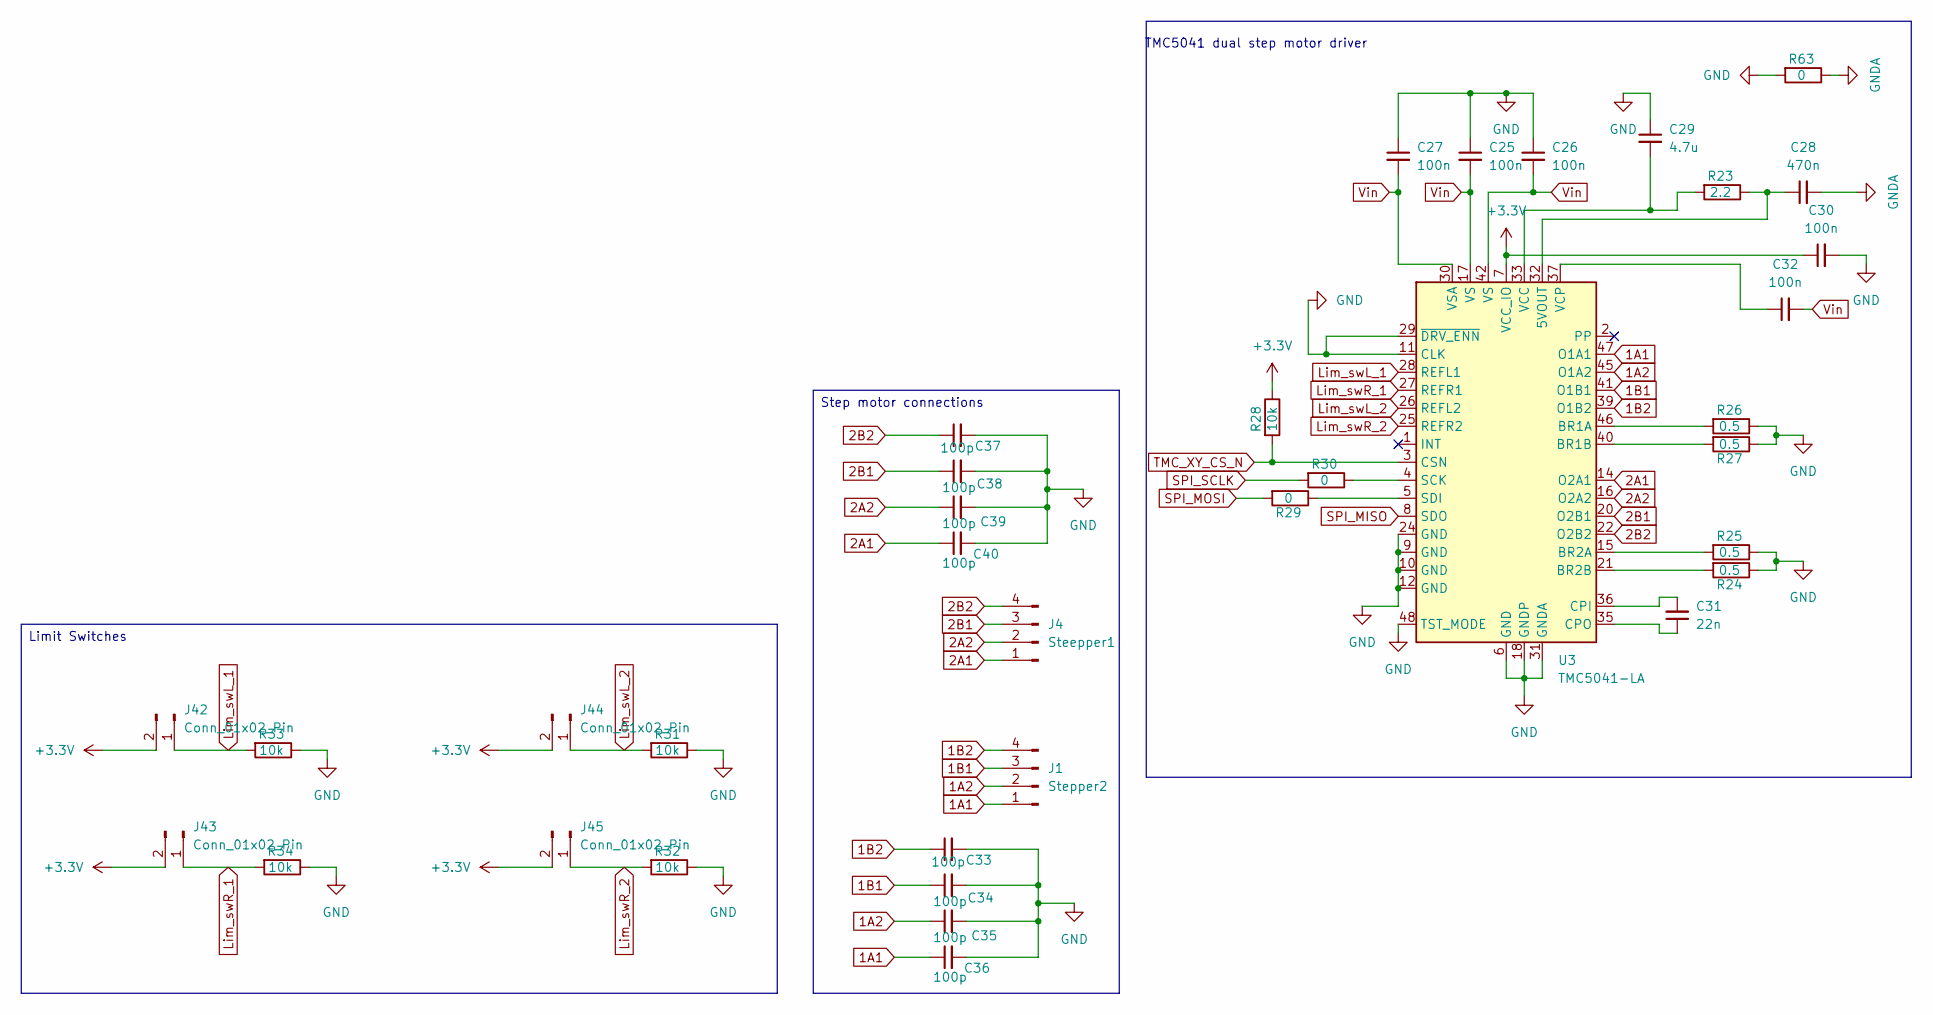
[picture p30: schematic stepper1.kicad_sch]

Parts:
C25, C26, C27, C30, C32: 100n; C_0402_1005Metric_Pad0.74x0.62mm_HandSolder; LCSC Part # C14663
C28: 470n; C_0402_1005Metric_Pad0.74x0.62mm_HandSolder; LCSC Part # C14663
C29: 4.7u; C_0402_1005Metric_Pad0.74x0.62mm_HandSolder; LCSC Part # C14663
C31: 22n; C_0402_1005Metric_Pad0.74x0.62mm_HandSolder; LCSC Part # C14663
C33, C34, C35, C36, C37, C38, C39, C40: 100p; C_0402_1005Metric_Pad0.74x0.62mm_HandSolder; LCSC Part # C14663
J1: Stepper2; PinHeader_1x04_P1.00mm_Vertical
J4: Steepper1; PinHeader_1x04_P1.00mm_Vertical
J42, J43, J44, J45: Conn_01x02_Pin; PinHeader_1x02_P1.00mm_Vertical
R23: 2.2; R_0402_1005Metric_Pad0.72x0.64mm_HandSolder; LCSC Part # C23182
R24, R25, R26, R27: 0.5; R_1206_3216Metric_Pad1.30x1.75mm_HandSolder; LCSC Part # C23182
R28, R31, R32, R33, R34: 10k; R_0402_1005Metric_Pad0.72x0.64mm_HandSolder; LCSC Part # C23182
R29, R30, R63: 0; R_0402_1005Metric_Pad0.72x0.64mm_HandSolder; LCSC Part # C23182
U3: TMC5041-LA; QFN-48-1EP_7x7mm_P0.5mm_EP5.3x5.3mm_ThermalVias

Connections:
1A1: C36.1, J1.1, U3.47 (O1A1)
1A2: C35.1, J1.2, U3.45 (O1A2)
1B1: C34.1, J1.3, U3.41 (O1B1)
1B2: C33.1, J1.4, U3.39 (O1B2)
2A1: C40.1, J4.1, U3.14 (O2A1)
2A2: C39.1, J4.2, U3.16 (O2A2)
2B1: C38.1, J4.3, U3.20 (O2B1)
2B2: C37.1, J4.4, U3.22 (O2B2)
GND: C25.1, C26.1, C27.1, C29.1, C30.2, C33.2, C34.2, C35.2, C36.2, C37.2, C38.2, C39.2, C40.2, R24.1, R25.1, R26.1, R27.1, R31.1, R32.1, R33.1, R34.1, R63.2, U3.6 (GND), U3.9 (GND), U3.10 (GND), U3.11 (CLK), U3.12 (GND), U3.13 (nc), U3.18 (GNDP), U3.23 (nc), U3.24 (GND), U3.29 (~DRV_ENN), U3.31 (GNDA), U3.34 (GND), U3.38 (nc), U3.43 (GNDP), U3.48 (TST_MODE), U3.49 (EP_GND); also elsewhere on the board
GNDA: C28.2, R63.1; also elsewhere on the board
Lim_swL_1: J42.1, R33.2, U3.28 (REFL1)
Lim_swL_2: J44.1, R31.2, U3.26 (REFL2)
Lim_swR_1: J43.1, R34.2, U3.27 (REFR1)
Lim_swR_2: J45.1, R32.2, U3.25 (REFR2)
unnamed: C28.1, R23.1, U3.32 (5VOUT)
unnamed: R26.2, U3.46 (BR1A)
unnamed: R27.2, U3.40 (BR1B)
unnamed: R25.2, U3.15 (BR2A)
unnamed: R24.2, U3.21 (BR2B)
unnamed: C31.2, U3.36 (CPI)
unnamed: C31.1, U3.35 (CPO)
unnamed: R30.1, U3.4 (SCK)
unnamed: R29.1, U3.5 (SDI)
unnamed: C29.2, R23.2, U3.33 (VCC)
unnamed: C32.1, U3.37 (VCP)
PS1: C30.1, J42.2, J43.2, J44.2, J45.2, R28.1, U3.7 (VCC_IO); also elsewhere on the board
SPI_MISO: U3.8 (SDO); also elsewhere on the board
SPI_MOSI: R29.2; also elsewhere on the board
SPI_SCLK: R30.2; also elsewhere on the board
TMC_XY_CS_N: R28.2, U3.3 (CSN); also elsewhere on the board
Vin: C25.2, C26.2, C27.2, C32.2, U3.17 (VS), U3.19 (VS), U3.30 (VSA), U3.42 (VS), U3.44 (VS); also elsewhere on the board

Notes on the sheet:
TMC5041 dual step motor driver
Limit Switches
Step motor connections

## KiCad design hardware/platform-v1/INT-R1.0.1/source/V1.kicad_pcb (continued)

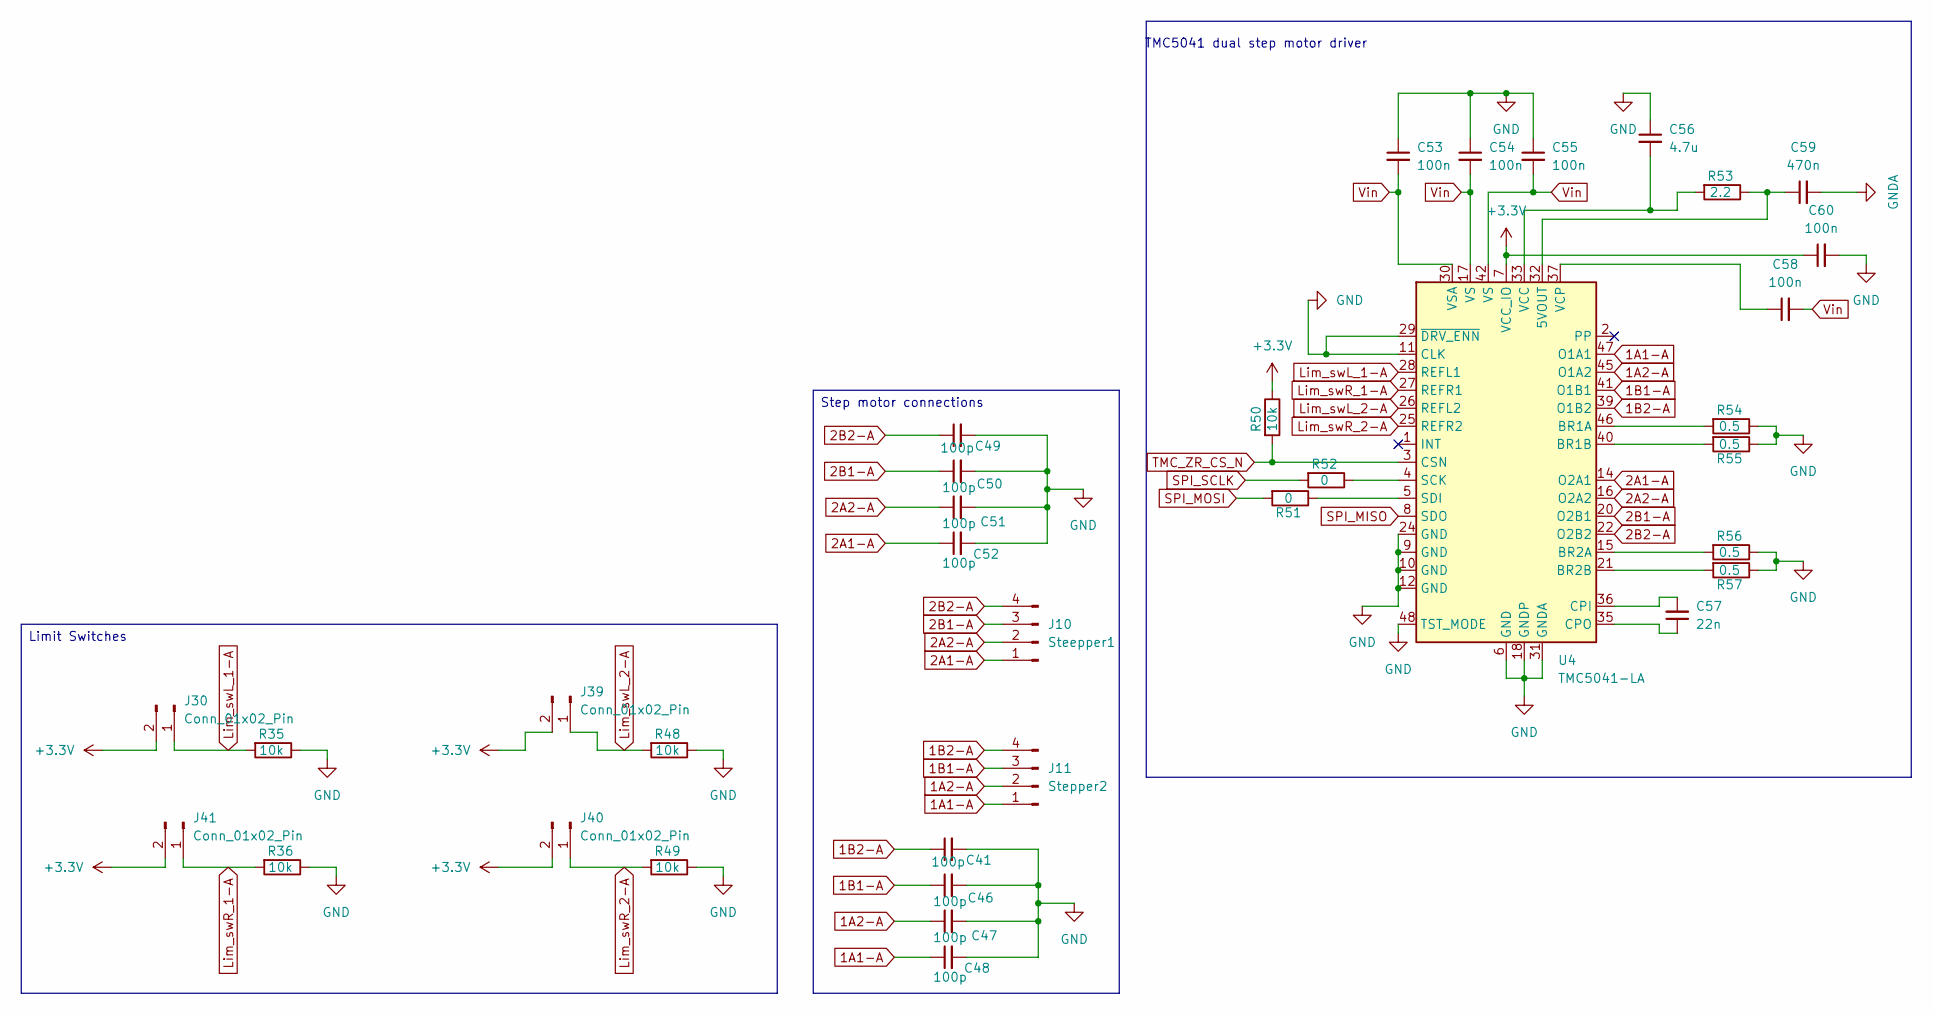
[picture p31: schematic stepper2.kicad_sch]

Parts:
C41, C46, C47, C48, C49, C50, C51, C52: 100p; C_0402_1005Metric_Pad0.74x0.62mm_HandSolder; LCSC Part # C14663
C53, C54, C55, C58, C60: 100n; C_0402_1005Metric_Pad0.74x0.62mm_HandSolder; LCSC Part # C14663
C56: 4.7u; C_0402_1005Metric_Pad0.74x0.62mm_HandSolder; LCSC Part # C14663
C57: 22n; C_0402_1005Metric_Pad0.74x0.62mm_HandSolder; LCSC Part # C14663
C59: 470n; C_0402_1005Metric_Pad0.74x0.62mm_HandSolder; LCSC Part # C14663
J10: Steepper1; PinHeader_1x04_P1.00mm_Vertical
J11: Stepper2; PinHeader_1x04_P1.00mm_Vertical
J30, J39, J40, J41: Conn_01x02_Pin; PinHeader_1x02_P1.00mm_Vertical
R35, R36, R48, R49, R50: 10k; R_0402_1005Metric_Pad0.72x0.64mm_HandSolder; LCSC Part # C23182
R51, R52: 0; R_0402_1005Metric_Pad0.72x0.64mm_HandSolder; LCSC Part # C23182
R53: 2.2; R_0402_1005Metric_Pad0.72x0.64mm_HandSolder; LCSC Part # C23182
R54, R55, R56, R57: 0.5; R_1206_3216Metric_Pad1.30x1.75mm_HandSolder; LCSC Part # C23182
U4: TMC5041-LA; QFN-48-1EP_7x7mm_P0.5mm_EP5.3x5.3mm_ThermalVias

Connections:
1A1-A: C48.1, J11.1, U4.47 (O1A1)
1A2-A: C47.1, J11.2, U4.45 (O1A2)
1B1-A: C46.1, J11.3, U4.41 (O1B1)
1B2-A: C41.1, J11.4, U4.39 (O1B2)
2A1-A: C52.1, J10.1, U4.14 (O2A1)
2A2-A: C51.1, J10.2, U4.16 (O2A2)
2B1-A: C50.1, J10.3, U4.20 (O2B1)
2B2-A: C49.1, J10.4, U4.22 (O2B2)
GND: C41.2, C46.2, C47.2, C48.2, C49.2, C50.2, C51.2, C52.2, C53.1, C54.1, C55.1, C56.1, C60.2, R35.1, R36.1, R48.1, R49.1, R54.1, R55.1, R56.1, R57.1, U4.6 (GND), U4.9 (GND), U4.10 (GND), U4.11 (CLK), U4.12 (GND), U4.13 (nc), U4.18 (GNDP), U4.23 (nc), U4.24 (GND), U4.29 (~DRV_ENN), U4.31 (GNDA), U4.34 (GND), U4.38 (nc), U4.43 (GNDP), U4.48 (TST_MODE), U4.49 (EP_GND); also elsewhere on the board
GNDA: C59.2; also elsewhere on the board
Lim_swL_1-A: J30.1, R35.2, U4.28 (REFL1)
Lim_swL_2-A: J39.1, R48.2, U4.26 (REFL2)
Lim_swR_1-A: J41.1, R36.2, U4.27 (REFR1)
Lim_swR_2-A: J40.1, R49.2, U4.25 (REFR2)
unnamed: C59.1, R53.1, U4.32 (5VOUT)
unnamed: R54.2, U4.46 (BR1A)
unnamed: R55.2, U4.40 (BR1B)
unnamed: R56.2, U4.15 (BR2A)
unnamed: R57.2, U4.21 (BR2B)
unnamed: C57.2, U4.36 (CPI)
unnamed: C57.1, U4.35 (CPO)
unnamed: R52.1, U4.4 (SCK)
unnamed: R51.1, U4.5 (SDI)
unnamed: C56.2, R53.2, U4.33 (VCC)
unnamed: C58.1, U4.37 (VCP)
PS1: C60.1, J30.2, J39.2, J40.2, J41.2, R50.1, U4.7 (VCC_IO); also elsewhere on the board
SPI_MISO: U4.8 (SDO); also elsewhere on the board
SPI_MOSI: R51.2; also elsewhere on the board
SPI_SCLK: R52.2; also elsewhere on the board
TMC_ZR_CS_N: R50.2, U4.3 (CSN); also elsewhere on the board
Vin: C53.2, C54.2, C55.2, C58.2, U4.17 (VS), U4.19 (VS), U4.30 (VSA), U4.42 (VS), U4.44 (VS); also elsewhere on the board

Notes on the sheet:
TMC5041 dual step motor driver
Limit Switches
Step motor connections

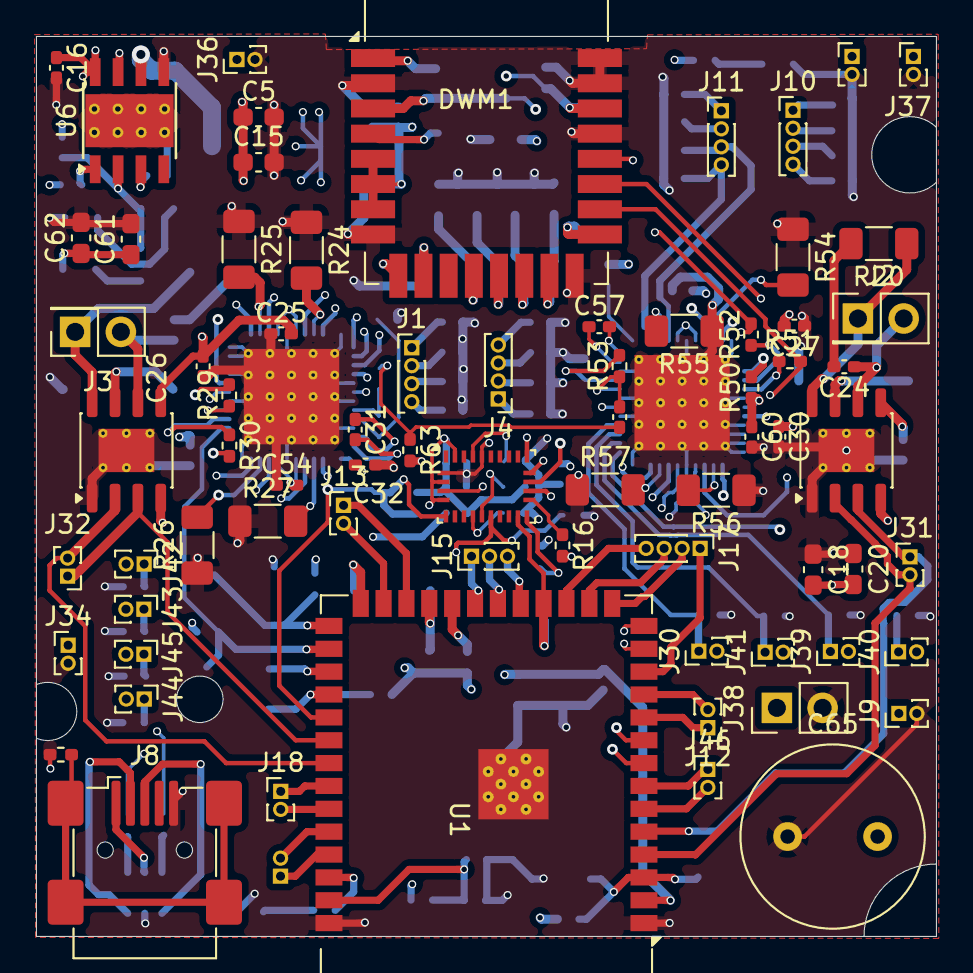
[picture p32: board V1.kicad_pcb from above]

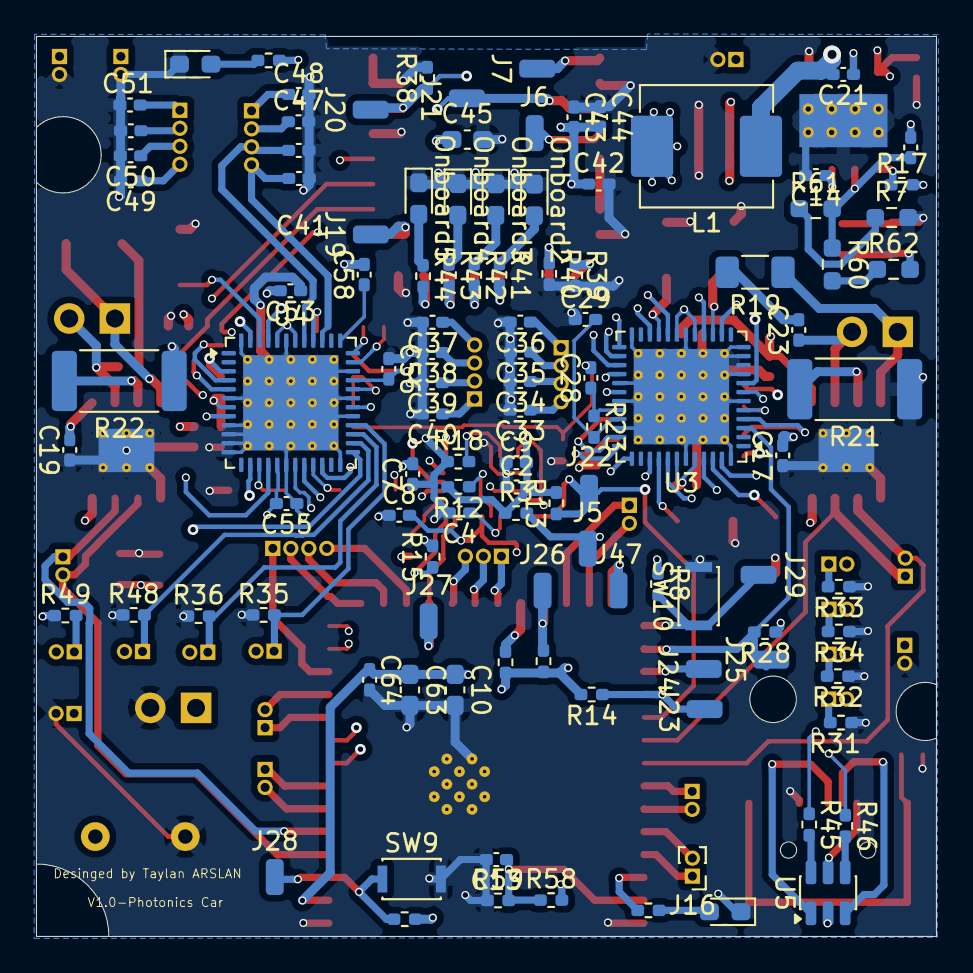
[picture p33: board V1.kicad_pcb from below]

Board: 8 copper layers, 50.0 x 50.0 mm, 182 parts (110 on the bottom side), 128 nets.

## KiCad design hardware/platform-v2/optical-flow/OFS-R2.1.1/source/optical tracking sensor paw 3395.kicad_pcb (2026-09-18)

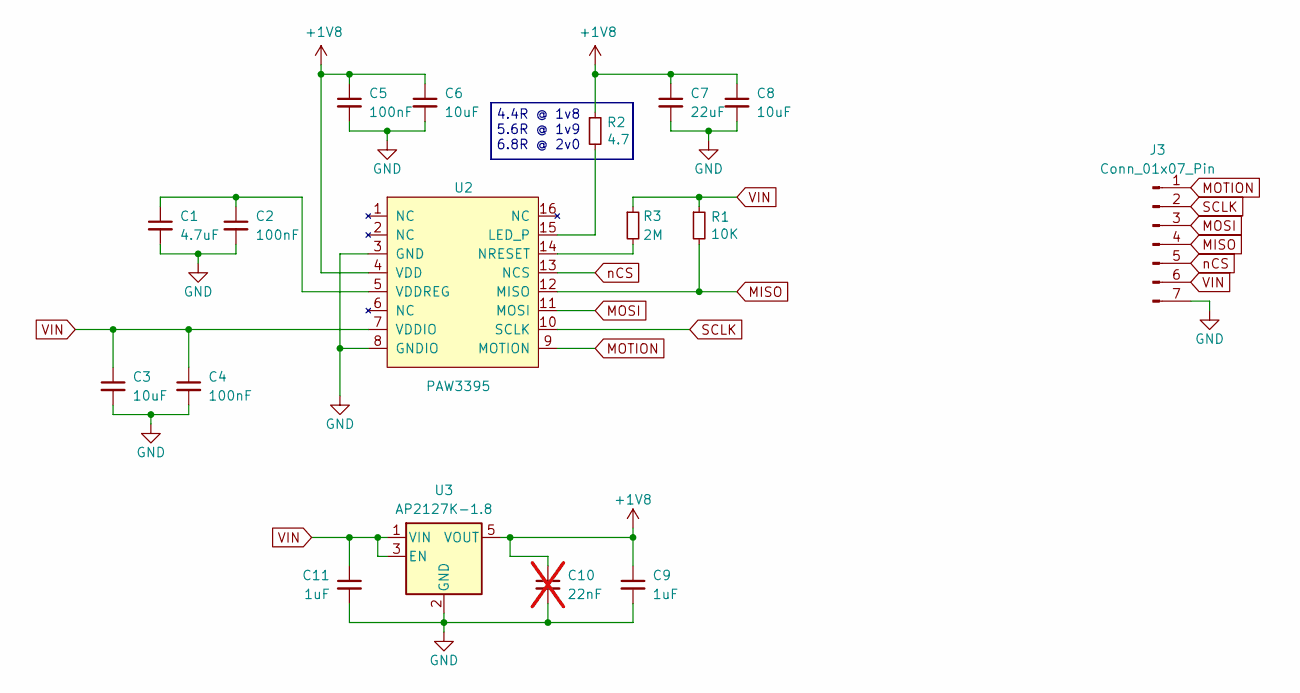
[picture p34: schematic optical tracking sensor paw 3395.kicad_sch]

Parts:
C1: 4.7uF; C_0603_1608Metric
C2, C4, C5: 100nF; C_0603_1608Metric
C3, C6, C8: 10uF; C_0603_1608Metric
C7: 22uF; C_0805_2012Metric
C9, C11: 1uF; C_0603_1608Metric
C10: 22nF; C_0603_1608Metric; not fitted
J3: Conn_01x07_Pin; 7 pin smd conn 2.54
R1: 10K; R_0603_1608Metric; LCSC C25804
R2: 4.7; R_0603_1608Metric; LCSC C23164
R3: 2M; R_0603_1608Metric; LCSC C22976
U2: PAW3395
U3: AP2127K-1.8; SOT-23-5

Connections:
+1V8: C5.1, C6.1, C7.1, C8.1, C9.1, C10.1, R2.1, U2.4 (VDD), U3.5 (VOUT)
GND: C1.2, C2.2, C3.2, C4.2, C5.2, C6.2, C7.2, C8.2, C9.2, C10.2, C11.2, J3.7, U2.3 (GND), U2.8 (GNDIO), U3.2 (GND)
MISO: J3.4, R1.2, U2.12 (MISO)
MOSI: J3.3, U2.11 (MOSI)
MOTION: J3.1, U2.9 (MOTION)
unnamed: R2.2, U2.15 (LED_P)
unnamed: R3.2, U2.14 (NRESET)
unnamed: C1.1, C2.1, U2.5 (VDDREG)
SCLK: J3.2, U2.10 (SCLK)
VIN: C3.1, C4.1, C11.1, J3.6, R1.1, R3.1, U2.7 (VDDIO), U3.1 (VIN), U3.3 (EN)
nCS: J3.5, U2.13 (NCS)

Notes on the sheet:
4.4R @ 1v8 5.6R @ 1v9 6.8R @ 2v0



Board: 2 copper layers, 19.3 x 24.0 mm, 17 parts (7 on the bottom side), 11 nets.

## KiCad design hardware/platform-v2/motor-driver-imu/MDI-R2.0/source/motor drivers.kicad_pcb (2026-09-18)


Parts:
BMO1: LGA-28_5.2x3.8mm_P0.5mm
C2: 4.7uF; C_0805_2012Metric_Pad1.18x1.45mm_HandSolder
C4, C7, C8, C9: 0.1uF; C_0805_2012Metric_Pad1.18x1.45mm_HandSolder
C21: 0.1u; C_0805_2012Metric_Pad1.18x1.45mm_HandSolder; LCSC Part # C14663
C25: 10u; C_0805_2012Metric_Pad1.18x1.45mm_HandSolder; LCSC Part # C5464883
C26: 100u; C_1206_3216Metric_Pad1.33x1.80mm_HandSolder; LCSC Part # C5464883
C27, C28: 100n; C_0805_2012Metric_Pad1.18x1.45mm_HandSolder; LCSC Part # C14663
J1: Conn_01x13_Pin; 13-conn-smd-dual
J4, J5, J8: Screw_Terminal_01x02; power pad dual
J6, J7: BNO_BOOT_Test_pin; SolderWirePad_1x01_SMD_1x2mm
R3, R4, R12, R13, R14, R18: 10k; R_0603_1608Metric_Pad0.98x0.95mm_HandSolder
R15, R16: 4.7k; R_0603_1608Metric_Pad0.98x0.95mm_HandSolder
R23, R24: 47; R_1206_3216Metric_Pad1.30x1.75mm_HandSolder; LCSC Part # C23182
TC78H651FNG1: TSSOP-16_4.4x5mm_P0.65mm

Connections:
BNO BOOTN: BMO1.4 (BOOTN), J6.1 (Pin_1_1), R3.2
GND: BMO1.2 (GND), BMO1.25 (GNDIO), C2.1, C4.2, C7.1, C8.1, C9.1, C21.1, C25.1, C26.1, J1.13, J8.1, R18.1, TC78H651FNG1.9 (GND)
IMU_CS_N: BMO1.18 (H_CSN), J1.2, R14.1
IMU_INT_N: BMO1.14 (H_INTN), J1.3
IMU_RST_N: BMO1.11 (NRST), C8.2, J1.1, R4.2
IMU_WAKE_N: BMO1.6 (PS0/WAKE), J7.1 (Pin_1_1), R13.1
MOTOR_L_IN1: J1.6, TC78H651FNG1.3 (IN4)
MOTOR_L_IN2: J1.10, TC78H651FNG1.4 (IN3)
MOTOR_R_IN1: J1.9, TC78H651FNG1.6 (IN1)
MOTOR_R_IN2: J1.8, TC78H651FNG1.7 (IN2)
Motor1_Out_+: J5.1, R24.1, TC78H651FNG1.14 (OUT3)
Motor1_Out_-: C28.1, J5.2, TC78H651FNG1.15 (OUT4)
Motor2_Out_+: J4.1, R23.1, TC78H651FNG1.11 (OUT2)
Motor2_Out_-: C27.1, J4.2, TC78H651FNG1.12 (OUT1)
unnamed: BMO1.9 (CAP), C4.1
unnamed: BMO1.10 (CLKSEL0), R12.1
unnamed: BMO1.26 (CLKSEL1/XOUT32), R18.2
unnamed: BMO1.15 (S_SCL), R15.1
unnamed: BMO1.16 (S_SDA), R16.1
unnamed: C27.2, R23.2
unnamed: C28.2, R24.2
PS1: BMO1.3 (VDD), BMO1.5 (PS1), BMO1.8 (nc), BMO1.28 (VDDIO), C2.2, C7.2, C9.2, J1.12, J8.2, R3.1, R4.1, R12.2, R13.2, R14.2, R15.2, R16.2
SPI_MISO: BMO1.20 (H_SDA/MISO/TX), J1.5
SPI_MOSI: BMO1.17 (H_SAO/MOSI), J1.11
SPI_SCLK: BMO1.19 (H_SCL/SCLK/RX), J1.4
Vin: C21.2, C25.2, C26.2, J1.7, TC78H651FNG1.1 (VM)

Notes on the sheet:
BNO085
Motor driver



Board: 4 copper layers, 25.0 x 27.0 mm, 28 parts (16 on the bottom side), 26 nets.

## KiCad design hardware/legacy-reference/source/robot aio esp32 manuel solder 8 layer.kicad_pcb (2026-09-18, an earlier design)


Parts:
C1, C12: 0.1u; C_1206_3216Metric; LCSC Part # C15850
C2, C3, C4, C10, C11: 10u; C_1206_3216Metric; LCSC Part # C15850
C5: 22p; C_1206_3216Metric; LCSC Part # C1653
C6, C15, C17, C19, C25, C26, C33: 0.1u; C_1206_3216Metric; LCSC Part # C14663
C7, C8, C14: 22u; C_1206_3216Metric; LCSC Part # C45783
C9: 0.47u; C_1206_3216Metric; LCSC Part # C1623
C16: 1u; C_1206_3216Metric; LCSC Part # C15849
C18, C20, C27, C28: 100u; C_Radial_D6.3mm_H5.0mm_P2.50mm; LCSC Part # C5464883
C23, C24, C31, C32: 100n; C_1206_3216Metric; LCSC Part # C14663
DRV8231DSGR2, DRV8231DSGR3, DRV8231DSGR4, DRV8231DSGR5: HSOP-8-1EP_3.9x4.9mm_P1.27mm_EP2.41x3.1mm_ThermalVias; LCSC Part # C3681197
FB1: 100 Ω @ 100 MHz; L_1206_3216Metric; LCSC Part # C1015
H1: MountingHole3; MountingHole_2.2mm_M2_DIN965_Pad_TopBottom
H2: MountingHole4; MountingHole_2.2mm_M2_DIN965_Pad_TopBottom
H3: MountingHole1; MountingHole_2.2mm_M2_DIN965_Pad_TopBottom
H5: MountingHole_Pad; MountingHole_2.2mm_M2_DIN965_Pad_TopBottom
J1: TC2030; PinHeader_2x03_P1.27mm_Vertical
J2, J3, J5, J6: Screw_Terminal_01x02; TerminalBlock_4Ucon_1x02_P3.50mm_Horizontal
J4: 5V; PinHeader_1x02_P1.27mm_Vertical
J7: ESP32 free gpio pins; PinHeader_1x14_P2.00mm_Vertical
J8: 3.3V; PinHeader_1x02_P1.27mm_Vertical
L1: 3.3u; L_10.4x10.4_H4.8
Onboard1: LED; LED_D3.0mm; LCSC Part # C2297
Outer1: LED; LED_D3.0mm
R1: 500k; R_0805_2012Metric_Pad1.20x1.40mm_HandSolder; LCSC Part # C21190
R2: 0; R_1206_3216Metric; LCSC Part # C4216
R10, R12, R27: 1k; R_1206_3216Metric; LCSC Part # C21190
R11: 3k; R_1206_3216Metric; LCSC Part # C4211
R13: 243K; R_1206_3216Metric; LCSC Part # C22807
R14: 33k; R_1206_3216Metric; LCSC Part # C4216
R16: 20k; R_1206_3216Metric; LCSC Part # C4184
R19, R20, R23, R24: 47; R_1206_3216Metric; LCSC Part # C23182
R25: 300k; R_1206_3216Metric; LCSC Part # C23024
R26: 56k; R_1206_3216Metric; LCSC Part # C23206
U1: ESP32-WROOM-32UE; LCSC Part # C529578
U2: AP7361C-33E; SOT-223-3_TabPin2
U3: TPS56528DDA; Texas_HSOP-8-1EP_3.9x4.9mm_P1.27mm_ThermalVias; LCSC Part # C138716

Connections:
+3.3V: C1.1, C11.1, DRV8231DSGR2.4 (VREF), DRV8231DSGR3.4 (VREF), DRV8231DSGR4.4 (VREF), DRV8231DSGR5.4 (VREF), FB1.2, J1.2, J7.1, J8.1, J8.2, R1.1, R10.2, R16.1, U2.3 (VO)
+5V: C5.1, C7.1, C8.1, C10.1, C12.1, J4.1, J4.2, L1.2, R13.2, U2.1 (VI)
EN: J1.1, R1.2, U1.3 (EN)
GND: C1.2, C2.2, C3.2, C4.2, C7.2, C8.2, C9.2, C10.2, C11.2, C12.2, C14.2, C15.1, C16.1, C17.1, C18.1, C19.1, C20.1, C25.1, C26.1, C27.1, C28.1, C33.2, DRV8231DSGR2.1 (GND), DRV8231DSGR2.7 (ISEN), DRV8231DSGR2.9 (PAD_GND), DRV8231DSGR3.1 (GND), DRV8231DSGR3.7 (ISEN), DRV8231DSGR3.9 (PAD_GND), DRV8231DSGR4.1 (GND), DRV8231DSGR4.7 (ISEN), DRV8231DSGR4.9 (PAD_GND), DRV8231DSGR5.1 (GND), DRV8231DSGR5.7 (ISEN), DRV8231DSGR5.9 (PAD_GND), H3.MP, J1.4, J7.9, Onboard1.1 (K), Outer1.1 (K), R2.2, R26.1, U1.1 (GND), U1.15 (GND), U1.38 (GND), U1.39 (GND), U2.2 (GND), U3.5 (GND), U3.9 (GND)
IO0: J1.6, U1.25 (IO0)
IO2: R11.2, U1.24 (IO2)
IO4: DRV8231DSGR2.2 (IN2), U1.26 (IO4)
IO5: DRV8231DSGR2.3 (IN1), U1.29 (IO5)
IO12: DRV8231DSGR5.2 (IN2), U1.14 (IO12)
IO13: DRV8231DSGR5.3 (IN1), U1.16 (IO13)
IO14: J7.2, U1.13 (IO14)
IO15: J7.3, U1.23 (IO15)
IO16: DRV8231DSGR3.2 (IN2), U1.27 (IO16)
IO17: DRV8231DSGR3.3 (IN1), U1.28 (IO17)
IO18: J7.4, U1.30 (IO18)
IO19: J7.5, U1.31 (IO19)
IO21: J7.6, U1.33 (IO21)
IO22: J7.7, U1.36 (IO22)
IO23: J7.8, U1.37 (IO23)
IO25: DRV8231DSGR4.2 (IN2), U1.10 (IO25)
IO26: DRV8231DSGR4.3 (IN1), U1.11 (IO26)
IO27: J7.10, U1.12 (IO27)
IO32: J7.11, U1.8 (IO32)
IO33: J7.12, U1.9 (IO33)
IO34: R16.2, U1.6 (IO34), U3.4 (PG)
IO35: J7.13, U1.7 (IO35)
IO_analog_ADC: J7.14, U1.5 (SENSOR_VN)
IO_analog_ADC_Battery_Meter: C33.1, R27.1, U1.4 (SENSOR_VP)
Motor1_Out_+: DRV8231DSGR2.8 (OUT2), J2.1, R20.1
Motor1_Out_-: C24.1, J2.2
Motor2_Out_+: DRV8231DSGR3.8 (OUT2), J3.1, R19.1
Motor2_Out_-: C23.1, DRV8231DSGR3.6 (OUT1), J3.2
Motor3_Out_+: DRV8231DSGR4.8 (OUT2), J6.1, R24.1
Motor3_Out_-: C32.1, DRV8231DSGR4.6 (OUT1), J6.2
Motor4_Out_+: DRV8231DSGR5.8 (OUT2), J5.1, R23.1
Motor4_Out_-: C31.1, DRV8231DSGR5.6 (OUT1), J5.2
unnamed: C23.2, R19.2
unnamed: C24.2, R20.2
unnamed: C31.2, R23.2
unnamed: C32.2, R24.2
unnamed: Onboard1.2 (A), R11.1
unnamed: Outer1.2 (A), R10.1
unnamed: R2.1, R14.1
unnamed: R25.1, R26.2, R27.2
unnamed: C14.1, C15.2, C16.2, FB1.1, U1.2 (VDD)
unnamed: R12.1, U3.1 (EN)
unnamed: C5.2, R13.1, R14.2, U3.2 (VFB)
unnamed: C9.1, U3.3 (VREG5)
SW: C6.2, L1.1, U3.6 (SW)
U0RX: J1.5, U1.34 (RXD0/IO3)
U0TX: J1.3, U1.35 (TXD0/IO1)
VBST: C6.1, U3.7 (VBST)
Vin: C2.1, C3.1, C4.1, C17.2, C18.2, C19.2, C20.2, C25.2, C26.2, C27.2, C28.2, DRV8231DSGR2.5 (VM), DRV8231DSGR3.5 (VM), DRV8231DSGR4.5 (VM), DRV8231DSGR5.5 (VM), H5.1, R12.2, R25.2, U3.8 (VIN)

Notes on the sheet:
ESP32
Brushed Motor Controllers X2
Brushed motor controllers X2
Reset, Boot switch and power LED, onboard LED
TPS56528DDA 5V
3.3V Lineer Regulator
Pins



Board: 8 copper layers, 50.0 x 46.2 mm, 66 parts (19 on the bottom side), 53 nets.

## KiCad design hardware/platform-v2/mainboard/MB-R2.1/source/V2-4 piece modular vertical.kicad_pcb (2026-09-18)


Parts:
C14: 22u; C_0805_2012Metric_Pad1.18x1.45mm_HandSolder; LCSC Part # C45783
C15, C33: 0.1u; C_0805_2012Metric_Pad1.18x1.45mm_HandSolder; LCSC Part # C14663
C16, C17: 1u; C_0805_2012Metric_Pad1.18x1.45mm_HandSolder; LCSC Part # C15849
C18: 10u; C_0805_2012Metric_Pad1.18x1.45mm_HandSolder; LCSC Part # C15849
C19: 4.7u; C_0805_2012Metric_Pad1.18x1.45mm_HandSolder; LCSC Part # C15849
C20: 100n; C_0805_2012Metric_Pad1.18x1.45mm_HandSolder; LCSC Part # C15849
FB1: 100 Ω @ 100 MHz; L_1206_3216Metric; LCSC Part # C1015
J1: TC2030; PinHeader_2x03_P1.27mm_Vertical
J2, J3: Conn_01x13_Pin; 13-conn-smd-dual
NCP1: XDFN-8, 1.6 × 1.2 mm, 0.4 mm pitch
Onboard1: LED; LED_0805_2012Metric_Pad1.15x1.40mm_HandSolder; LCSC Part # C2297
Outer1: LED; LED_0805_2012Metric_Pad1.15x1.40mm_HandSolder
R8, R28: 10k; R_0805_2012Metric_Pad1.20x1.40mm_HandSolder; LCSC Part # C21190
R10, R27: 1k; R_0805_2012Metric_Pad1.20x1.40mm_HandSolder; LCSC Part # C21190
R11: 3k; R_0805_2012Metric_Pad1.20x1.40mm_HandSolder; LCSC Part # C4211
R25: 300k; R_0805_2012Metric_Pad1.20x1.40mm_HandSolder; LCSC Part # C23024
R26: 56k; R_0805_2012Metric_Pad1.20x1.40mm_HandSolder; LCSC Part # C23206
SW9, SW10: SW_Push; SW_SPST_CK_KXT3
U4: ESP32-WROOM-32UE; LCSC Part # C529578

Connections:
+3.3V: C18.1, C20.1, FB1.2, J1.2, J2.1, J3.10, J3.11, NCP1.1 (OUT), NCP1.2 (OUT), NCP1.4 (FB), R8.1, R10.2, R25.2, R28.1
EN: C17.2, J1.1, R28.2, SW9.1, U4.3 (EN)
ESP_BOOT: J1.6, R8.2, SW10.1, U4.25 (IO0)
GND: C14.2, C15.1, C16.1, C17.1, C18.2, C19.1, C20.2, C33.2, J1.4, J2.2, J3.1, J3.13, NCP1.5 (GND), NCP1.9 (PAD/GND), Onboard1.1 (K), Outer1.1 (K), R26.1, SW9.2, SW10.2, U4.1 (GND), U4.15 (GND), U4.38 (GND), U4.39 (GND)
IO2: U4.24 (IO2)
IO4: J3.9, U4.26 (IO4)
IO5: U4.29 (IO5)
IO12: J2.12, U4.14 (IO12)
IO13: J2.13, R11.2, U4.16 (IO13)
IO14: J2.11, U4.13 (IO14)
IO15: U4.23 (IO15)
IO16: J3.8, U4.27 (IO16)
IO17: J3.7, U4.28 (IO17)
IO18: J3.6, U4.30 (IO18)
IO19: J3.5, U4.31 (IO19)
IO21-SDA: J3.4, U4.33 (IO21)
IO22-SCL: J3.3, U4.36 (IO22)
IO23: J3.2, U4.37 (IO23)
IO25: J2.8, U4.10 (IO25)
IO26: J2.9, U4.11 (IO26)
IO27: J2.10, U4.12 (IO27)
IO32: J2.6, U4.8 (IO32)
IO33: J2.7, U4.9 (IO33)
IO34: J2.4, U4.6 (IO34)
IO35: J2.5, U4.7 (IO35)
IO_analog_ADC: J2.3, U4.5 (SENSOR_VN)
IO_analog_ADC_Battery_Meter: C33.1, R27.1, U4.4 (SENSOR_VP)
unnamed: Onboard1.2 (A), R11.1
unnamed: Outer1.2 (A), R10.1
unnamed: R25.1, R26.2, R27.2
unnamed: C14.1, C15.2, C16.2, FB1.1, U4.2 (VDD)
U0RX: J1.5, U4.34 (RXD0/IO3)
U0TX: J1.3, U4.35 (TXD0/IO1)
Vin: C19.2, J3.12, NCP1.6 (EN), NCP1.7 (IN), NCP1.8 (IN)

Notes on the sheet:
Buttons



Board: 4 copper layers, 25.0 x 27.1 mm, 25 parts (13 on the bottom side), 31 nets.

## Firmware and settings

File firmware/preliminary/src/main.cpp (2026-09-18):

#include <Arduino.h>
#include "board_config.h"
#include "hbridge.h"
#include "sensor_interfaces.h"

HBridgeMotor leftMotor(apc::PIN_MOTOR_L_IN1, apc::PIN_MOTOR_L_IN2);
HBridgeMotor rightMotor(apc::PIN_MOTOR_R_IN1, apc::PIN_MOTOR_R_IN2);
Sensors sensors;

static unsigned long lastHeartbeatMs = 0;
static bool ledState = false;

void stopAll() {
    leftMotor.stop();
    rightMotor.stop();
}

void printStatus() {
    Serial.println("--- Autonomous-Photonics-Carrier / Platform V2 ---");
    Serial.printf("uptime_ms=%lu\n", millis());
    Serial.printf("status_led_gpio=%d\n", apc::PIN_STATUS_LED);
    Serial.printf("adc36_raw=%d\n", analogRead(apc::PIN_ADC_DIAGNOSTIC));
    Serial.printf("left_motor_mapped=%s\n", leftMotor.available() ? "yes" : "no");
    Serial.printf("right_motor_mapped=%s\n", rightMotor.available() ? "yes" : "no");
    Serial.println("sensors=preliminary stubs (BNO086 / PAW3395 / MA730 not yet integrated)");
}

void handleCommand(String line) {
    line.trim();
    if (line.length() == 0) return;

    if (line == "help") {
        Serial.println("Commands: help, status, stop, motor <left -1..1> <right -1..1>");
        return;
    }

    if (line == "status") {
        printStatus();
        return;
    }

    if (line == "stop") {
        stopAll();
        Serial.println("motors stopped");
        return;
    }

    if (line.startsWith("motor ")) {
        if (!leftMotor.available() || !rightMotor.available()) {
            Serial.println("REFUSED: motor GPIO mapping is disabled in board_config.h");
            return;
        }

        float left = 0.0f, right = 0.0f;
        if (sscanf(line.c_str(), "motor %f %f", &left, &right) == 2) {
            leftMotor.set(left);
            rightMotor.set(right);
            Serial.printf("motor command accepted: L=%.3f R=%.3f\n", left, right);
        } else {
            Serial.println("usage: motor <left -1..1> <right -1..1>");
        }
        return;
    }

    Serial.println("unknown command; type 'help'");
}

void setup() {
    pinMode(apc::PIN_STATUS_LED, OUTPUT);
    digitalWrite(apc::PIN_STATUS_LED, LOW);

    Serial.begin(115200);
    delay(250);

    leftMotor.begin();
    rightMotor.begin();
    sensors.begin();
    stopAll();

    Serial.println();
    Serial.println("Autonomous-Photonics-Carrier preliminary firmware");
    Serial.println("No autonomous motion is enabled. Type 'help'.");

    if (apc::ENABLE_ACTUATION_AT_BOOT) {
        Serial.println("WARNING: ENABLE_ACTUATION_AT_BOOT is true, but no automatic motion is implemented.");
    }

    printStatus();
}

void loop() {
    const unsigned long now = millis();
    if (now - lastHeartbeatMs >= 500) {
        lastHeartbeatMs = now;
        ledState = !ledState;
        digitalWrite(apc::PIN_STATUS_LED, ledState ? HIGH : LOW);
    }

    if (Serial.available()) {
        String line = Serial.readStringUntil('\n');
        handleCommand(line);
    }

    // Future control loop:
    // 1) sample wheel angle, optical flow and IMU;
    // 2) timestamp/synchronise measurements;
    // 3) update pose estimator;
    // 4) accept a velocity/pose target from the host;
    // 5) compute left/right motor commands with explicit safety limits;
    // 6) stream telemetry for reproducibility.

    delay(2);
}

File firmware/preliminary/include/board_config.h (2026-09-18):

#pragma once

// Autonomous-Photonics-Carrier — Platform V2 preliminary firmware
// Public scaffold: peripheral mappings remain disabled until the final
// physical daughterboard interconnect is confirmed on the assembled carrier.

namespace apc {

// Confirmed directly from MB-R2.1 PCB routing.
constexpr int PIN_STATUS_LED = 13;

// ESP32-WROOM-32UE pad 4 / SENSOR_VP corresponds to GPIO36 and is labelled
// IO_analog_ADC_Battery_Meter in the current mainboard source. The resistor
// network should be re-checked before interpreting this as true battery voltage.
constexpr int PIN_ADC_DIAGNOSTIC = 36;

// Use -1 to make a signal unavailable. The firmware will not actuate motors
// until every required motor pin has a non-negative mapping.
constexpr int PIN_MOTOR_L_IN1 = -1;
constexpr int PIN_MOTOR_L_IN2 = -1;
constexpr int PIN_MOTOR_R_IN1 = -1;
constexpr int PIN_MOTOR_R_IN2 = -1;

constexpr int PIN_IMU_CS_N   = -1;
constexpr int PIN_IMU_INT_N  = -1;
constexpr int PIN_IMU_RST_N  = -1;
constexpr int PIN_SPI_SCLK   = -1;
constexpr int PIN_SPI_MOSI   = -1;
constexpr int PIN_SPI_MISO   = -1;

constexpr int PIN_PAW_NCS    = -1;
constexpr int PIN_PAW_MOTION = -1;
constexpr int PIN_MA730_CS_L = -1;
constexpr int PIN_MA730_CS_R = -1;

constexpr bool ENABLE_ACTUATION_AT_BOOT = false;

} // namespace apc
